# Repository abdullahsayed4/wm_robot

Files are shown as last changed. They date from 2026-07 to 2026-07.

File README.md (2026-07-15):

# WM Robot — Autonomous Mobile Robot for Warehouse Operations





> **Graduation Project** — Faculty of Engineering at Shoubra, Benha University  
> Department of Mechanical & Mechatronics Engineering · 2024–2025  
> **Supervisor:** Dr. Mahmoud Mohamed El-Samanti

---

## Overview

WM Robot is a fully autonomous differential-drive mobile robot designed for indoor warehouse environments. It performs pickup-and-dropoff tasks without human intervention by combining embedded motor control, sensor fusion, autonomous navigation, and a web-based mission interface.

WM Robot

---

## System Architecture

```
┌─────────────────────────────────────────────────────┐
│                   ROS 2 (Jazzy)                     │
│                                                     │
│  ┌──────────────┐    ┌──────────────┐    ┌───────┐  │
│  │ wm_robot_    │    │ wm_robot_    │    │ Nav2  │  │
│  │ hardware     │    │ bringup      │    │ Stack │  │
│  │ (C++)        │    │ (Launch/Cfg) │    │       │  │
│  └──────┬───────┘    └──────────────┘    └───────┘  │
│         │                                           │
│  ┌──────▼───────┐    ┌──────────────┐              │
│  │  TeensyDriver│    │  IMU Node    │              │
│  │  (Serial)    │    │  (Python)    │              │
│  └──────┬───────┘    └──────┬───────┘              │
└─────────│──────────────────│─────────────────────┘
          │                  │
    ┌─────▼──────┐    ┌──────▼───────┐    ┌──────────┐
    │ Teensy 4.1 │    │ Arduino Uno  │    │ RPLIDAR  │
    │ (PID + Enc)│    │ (BNO055 IMU  │    │    A1    │
    └────────────┘    │ + Actuator)  │    └──────────┘
                      └──────────────┘
```

---

## Hardware

| Component | Details |
|---|---|
| **Chassis** | Differential-drive, custom-built |
| **Microcontroller** | Teensy 4.1 (motor PID + encoders) |
| **IMU Controller** | Arduino Uno (BNO055 IMU + linear actuator) |
| **LiDAR** | RPLIDAR A1 |
| **IMU** | BNO055 (9-DOF) |
| **Motors** | DC motors with encoders |
| **Motor Driver** | Cytron |
| **Lift Mechanism** | Scissor lift + linear actuator + limit switches |
| **Joystick** | PlayStation 4 (Bluetooth) |
| **Compute** | Raspberry Pi 4 (ROS 2 host) |

---

## Software Stack

| Layer | Technology |
|---|---|
| **OS** | Ubuntu 24.04 |
| **Middleware** | ROS 2 Jazzy |
| **SLAM** | SLAM Toolbox |
| **Navigation** | Nav2 (AMCL + DWB) |
| **State Estimation** | robot_localization (EKF) |
| **Motor Control** | Custom C++ hardware interface (ros2_control) |
| **IMU Driver** | Python serial node |
| **Mission UI** | React (web-based) |

---

## Repository Structure

```
wm_robot/
├── src/
│   ├── wm_robot_project/        # URDF, meshes, Gazebo worlds, RViz
│   │   ├── urdf/                # Xacro robot description
│   │   ├── meshes/              # STL files (base, wheels, LiDAR, casters)
│   │   ├── launch/              # Display & Gazebo simulation launch
│   │   └── worlds/              # Gazebo SDF world
│   │
│   ├── wm_robot_hardware/       # C++ hardware interface & drivers
│   │   ├── src/
│   │   │   ├── robot_node.cpp               # Main ROS 2 node (50Hz control loop)
│   │   │   ├── cytron_driver.cpp            # Teensy serial driver
│   │   │   └── wm_robot_base_hardware_interface.cpp  # ros2_control plugin
│   │   ├── include/
│   │   │   ├── cytron_driver.hpp
│   │   │   └── wm_robot_base_hardware_interface.hpp
│   │   └── scripts/
│   │       └── imu_node.py      # IMU + actuator node (Arduino Uno)
│   │
│   ├── wm_robot_firmware/       # Arduino/Teensy firmware
│   │   └── firmware/
│   │       └── serial_transmitter/  # Teensy serial protocol
│   │
│   ├── wm_robot_bringup/        # Launch files & configuration
│   │   ├── launch/
│   │   │   ├── robot_launch.py       # Bring up hardware (robot + LiDAR + IMU)
│   │   │   └── navigation_launch.py  # Nav2 navigation stack
│   │   └── config/
│   │       ├── nav2_params.yaml           # Nav2 tuning
│   │       ├── ekf_config.yaml            # EKF sensor fusion
│   │       ├── wm_robot_controllers.yaml  # ros2_control config
│   │       └── Joy_stick.yaml             # PS4 joystick mapping
│   │
│   └── rplidar_ros/             # RPLIDAR A1 ROS 2 driver
│
├── maps/                        # Pre-built occupancy grid maps
│   ├── my_map1.yaml / .pgm
│   ├── my_map2.yaml / .pgm
│   └── my_map3.yaml / .pgm
│
├── start_robot.sh               # Quick startup script
└── README.md
```

---

## Getting Started

### Prerequisites

```bash
# ROS 2 Jazzy
sudo apt install ros-jazzy-desktop

# Dependencies
sudo apt install ros-jazzy-nav2-bringup \
                 ros-jazzy-slam-toolbox \
                 ros-jazzy-robot-localization \
                 ros-jazzy-ros2-control \
                 ros-jazzy-ros2-controllers \
                 ros-jazzy-joy \
                 ros-jazzy-teleop-twist-joy
```

### Build

```bash
mkdir -p ~/wm_robot_ws/src
cd ~/wm_robot_ws/src
git clone https://github.com/YOUR_USERNAME/wm_robot.git .
cd ~/wm_robot_ws
colcon build --symlink-install
source install/setup.bash
```

### Run

**Step 1 — Bring up the robot hardware:**
```bash
ros2 launch wm_robot_bringup robot_launch.py
```

**Step 2 — Start IMU + actuator node:**
```bash
ros2 run wm_robot_hardware imu_node
```

**Step 3 — Run SLAM (mapping mode):**
```bash
ros2 launch slam_toolbox online_async_launch.py
```

**Step 4 — Start navigation with existing map:**
```bash
ros2 launch wm_robot_bringup navigation_launch.py \
  map:=/path/to/maps/my_map1.yaml
```

**Step 5 — Manual control (PS4 Joystick):**
```bash
ros2 launch teleop_twist_joy teleop-launch.py
```

---

## Key Features

- **Autonomous Navigation** — SLAM Toolbox for mapping, Nav2 for localization and path planning
- **Dual PID Control** — Independent PID loops per wheel (MATLAB-tuned + Arduino PID_v1)
- **Sensor Fusion** — LiDAR + IMU + wheel odometry fused via EKF
- **Scissor Lift** — Linear actuator with limit switches for precise payload handling
- **Mock Hardware Mode** — Test navigation without physical robot (`use_mock_hardware:=true`)
- **Web Mission Interface** — React-based UI for mission assignment and monitoring
- **PS4 Teleoperation** — Bluetooth joystick for manual driving during mapping

---

## Serial Protocol

### Teensy 4.1 (ttyACM0) — Motor Controller
- Baud: `115200`
- Format: `A{posL}B{posR}C{velL}D{velR}` (position in rad, velocity in rad/s)

### Arduino Uno (ttyACM1) — IMU + Actuator
- Baud: `115200`
- IMU output: `IMU,{seq},{qw},{qx},{qy},{qz},{gx},{gy},{gz},{ax},{ay},{az},{cal_sys},{cal_gyro},{cal_acc},{cal_mag}`
- Actuator commands: `1\n` (lift up) / `0\n` (lower down)
- Actuator feedback: `LIFT_DONE` / `LOWER_DONE`

---

## Team

| Name |
|------|
| Abdullah Sayed |
| Abanoub Osama |
| Elsayed Azab |
| Amir Magdy |
| Youssef Omar |
| Nourhan Nagy |

**Supervisor:** Dr. Mahmoud Mohamed El-Samanti  
**Institution:** Faculty of Engineering at Shoubra, Benha University

---

## License

This project is licensed under the MIT License — see [LICENSE](LICENSE) for details.

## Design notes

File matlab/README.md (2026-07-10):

# Motor Control — PID Tuning & Low-Pass Filter

This folder contains all MATLAB/Simulink work done for motor system identification, PID tuning, and digital low-pass filter design.

---

## Folder Structure

```
matlab/
├── pid_tuning/
│   ├── pid_tuning.slx       # Simulink model for PID tuning (System Identification)
│   └── importfile.m         # MATLAB script to import collected motor data
│
├── low_pass_filter/
│   ├── LowPassFilter.ipynb              # Low-pass filter design
│   ├── ButterworthFilter.ipynb          # Butterworth filter implementation
│   ├── Analytic Derivation for Low-Pass 2.0.ipynb  # Mathematical derivation
│   └── filter_response.png              # Filter frequency response plot
│
└── firmware/
    ├── motor1_pid.ino        # Motor 1 — Custom PID + Digital Filter (Teensy)
    └── motor2_pid.ino        # Motor 2 — Two-motor PID implementation
```

---

## PID Parameters (Motor 1)

Tuned via MATLAB System Identification Toolbox from real motor step response data:

| Parameter | Value |
|---|---|
| **Kp** | 19.15 |
| **Ki** | 306.0 |
| **Kd** | 0.055 |
| **Sample Time** | 20 ms (50 Hz) |
| **Output Limits** | -250 to +250 (PWM) |

---

## Low-Pass Filter Design

A 2nd-order digital low-pass filter was derived analytically using the **Bilinear Transform** (Tustin method):

- **Cutoff Frequency:** Fc = 2.5 Hz
- **Sample Time:** dt = 0.020 s
- **Method:** Butterworth → Bilinear Transform

**Filter Coefficients:**
```
alpha = 0.728490
beta  = 0.135755
```

**Difference Equation:**
```
y[n] = alpha * y[n-1] + beta * x[n] + beta * x[n-1]
```

The filter smooths raw encoder velocity readings before feeding them into the PID controller, eliminating electrical noise without introducing significant lag.

---

## Methodology

1. **Data Collection** — Motor driven open-loop, encoder data logged via Serial at 50 Hz
2. **System Identification** — MATLAB `System Identification Toolbox` used to fit a transfer function to the collected step response data
3. **PID Tuning** — Simulink PID Tuner used to find optimal Kp, Ki, Kd
4. **Filter Design** — Butterworth filter analytically derived and discretized via Bilinear Transform
5. **Validation** — PID + filter tested on real hardware with square wave setpoint tracking

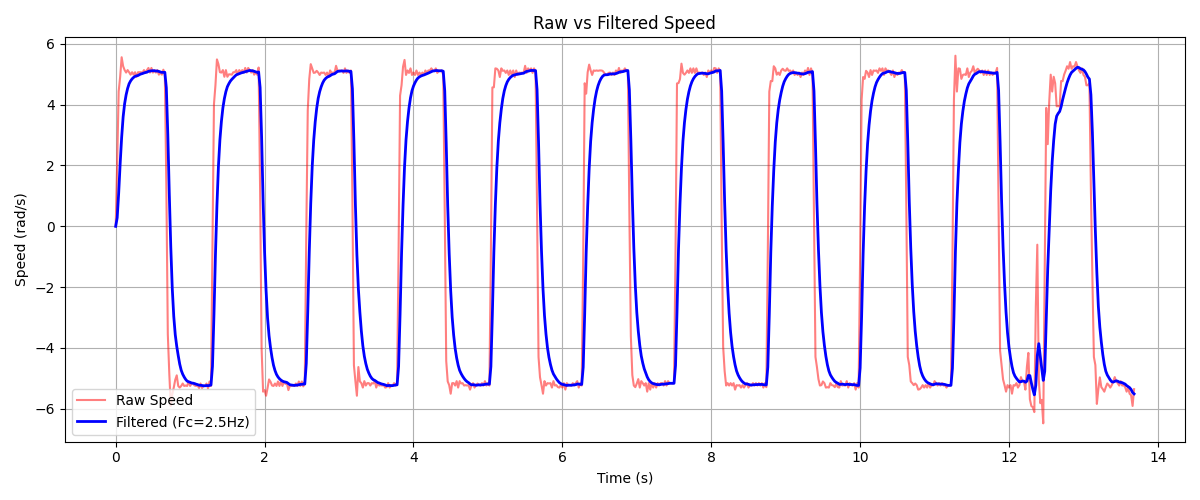
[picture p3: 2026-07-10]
matlab/low_pass_filter/filter_response.png

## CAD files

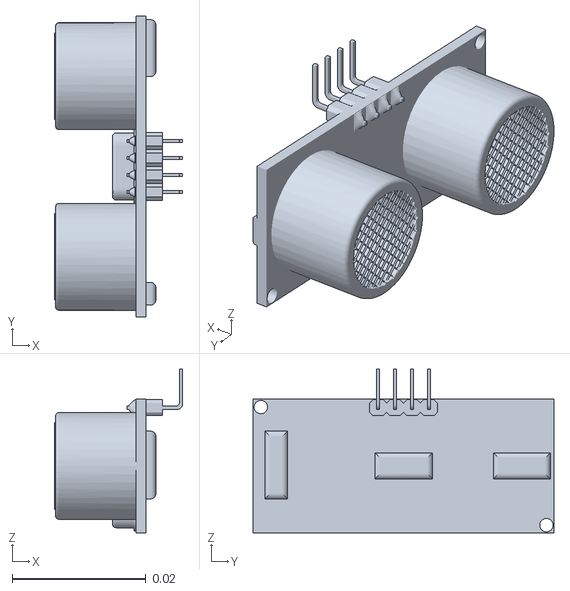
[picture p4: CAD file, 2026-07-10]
src/wm_robot_project/meshes/soni2.STL
0.0192 x 0.045 x 0.0245

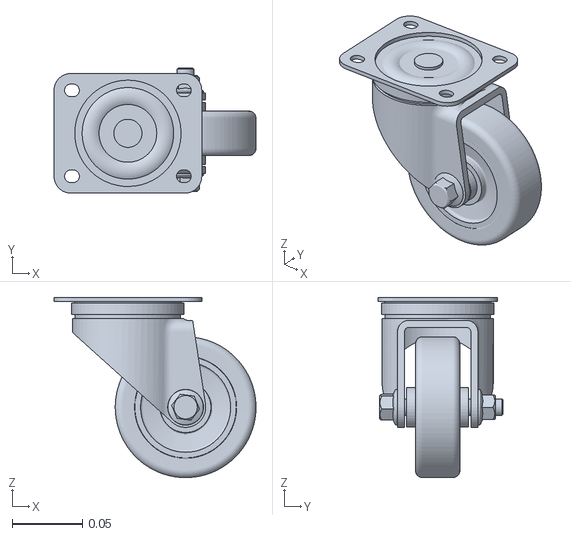
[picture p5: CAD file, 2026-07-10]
src/wm_robot_project/meshes/caster1.STL
0.143 x 0.089 x 0.128

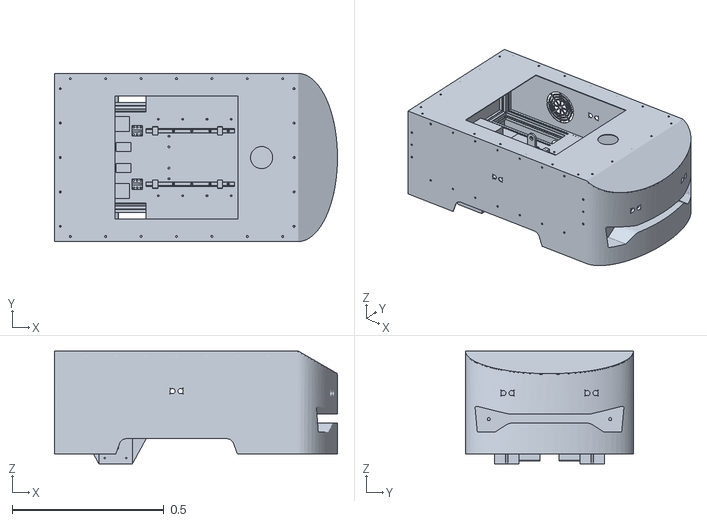
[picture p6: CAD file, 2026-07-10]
src/wm_robot_project/meshes/base_link.STL
0.932 x 0.554 x 0.372

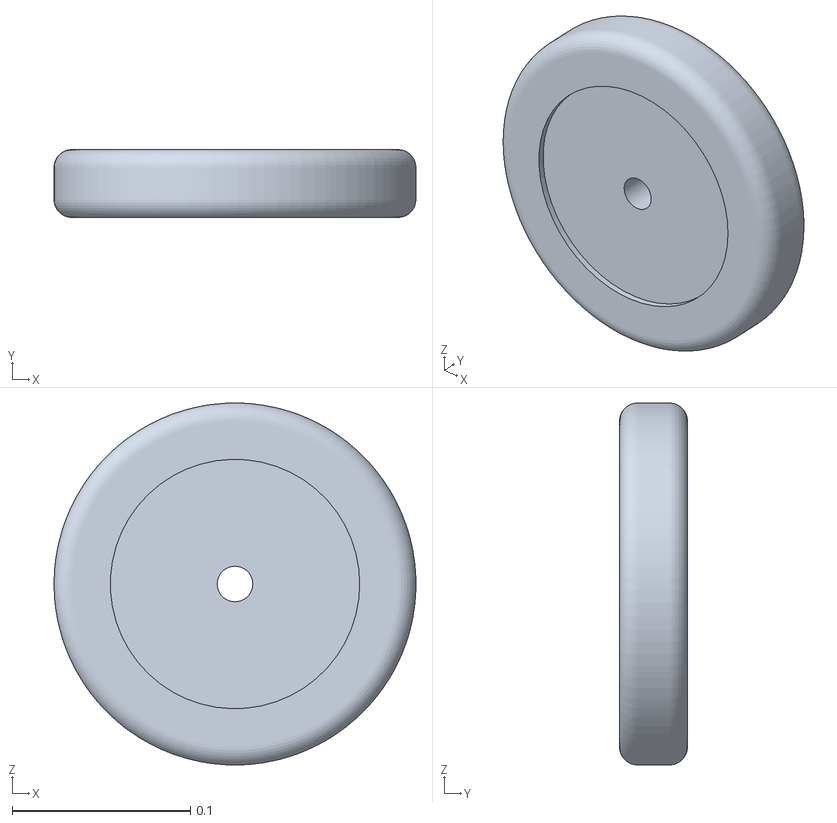
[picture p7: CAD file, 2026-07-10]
src/wm_robot_project/meshes/wheel1.STL
0.203 x 0.0381 x 0.203

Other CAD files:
src/wm_robot_project/meshes/soni3.STL
src/wm_robot_project/meshes/soni5.STL
src/wm_robot_project/meshes/caster2.STL
src/wm_robot_project/meshes/soni1.STL
src/wm_robot_project/meshes/wheel2.STL
src/wm_robot_project/meshes/soni4.STL

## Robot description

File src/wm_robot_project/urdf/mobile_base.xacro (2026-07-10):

<?xml version="1.0"?>
<robot xmlns:xacro="http://www.ros.org/wiki/xacro">
    <xacro:property name="wheel_radius" value="0.1"/>
    <xacro:property name="wheel_length" value="0.05"/>
    <xacro:macro name="cylinder_inertia" params="m r l o_xyz o_rpy">
        <inertial>
            <mass value="${m}"/>
            <origin xyz="${o_xyz}" rpy="${o_rpy}"/>
            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
        </inertial>
    </xacro:macro>

    <xacro:macro name="sphere_inertia" params="m r o_xyz o_rpy">
        <inertial>
            <mass value="${m}"/>
            <origin xyz="${o_xyz}" rpy="${o_rpy}"/>
            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
        </inertial>
    </xacro:macro>
  <link name="base_footprint"/>

  <link name="base_link">
    <inertial>
      <origin xyz="0.0037146 -0.00045656 0.12116" rpy="0 0 0" />
      <mass value="25.079" />
      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
    </inertial>
    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
  </link>

  <link name="soni1">
    <inertial>
      <origin xyz="-0.0025046 -1.8888E-05 -4.9385E-05" rpy="0 0 0" />
      <mass value="0.0044896" />
      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
    </inertial>
    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
  </link>

  <joint name="s_j1" type="fixed">
    <origin xyz="-0.3965 0 0.185" rpy="0 0 0" />
    <parent link="base_link" />
    <child link="soni1" />
  </joint>

  <link name="soni2">
    <inertial>
      <origin xyz="-0.0025046 -1.8888E-05 -4.9385E-05" rpy="0 0 0" />
      <mass value="0.0044896" />
      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
    </inertial>
    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
  </link>

  <joint name="s_j2" type="fixed">
    <origin xyz="0 0.2715 0.185" rpy="-3.1416 0 -1.5708" />
    <parent link="base_link" />
    <child link="soni2" />
  </joint>

  <link name="soni3">
    <inertial>
      <origin xyz="-0.0025046 -1.8888E-05 -4.9385E-05" rpy="0 0 0" />
      <mass value="0.0044896" />
      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
    </inertial>
    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
  </link>

  <joint name="s_j3" type="fixed">
    <origin xyz="0.49478 -0.1384 0.1784" rpy="3.1416 0 3.1416" />
    <parent link="base_link" />
    <child link="soni3" />
  </joint>

  <link name="soni4">
    <inertial>
      <origin xyz="-0.0025046 -1.8888E-05 -4.9385E-05" rpy="0 0 0" />
      <mass value="0.0044896" />
      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
    </inertial>
    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
  </link>

  <joint name="s_j4" type="fixed">
    <origin xyz="0.49449 0.1384 0.1784" rpy="3.1416 0 3.1416" />
    <parent link="base_link" />
    <child link="soni4" />
  </joint>

  <link name="soni5">
    <inertial>
      <origin xyz="-0.0025046 -1.8888E-05 -4.9385E-05" rpy="0 0 0" />
      <mass value="0.0044896" />
      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
    </inertial>
    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
  </link>

  <joint name="s_j5" type="fixed">
    <origin xyz="0 -0.2715 0.185" rpy="0 0 1.5708" />
    <parent link="base_link" />
    <child link="soni5" />
  </joint>

  <link name="wheel1">
    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
    <xacro:cylinder_inertia m="1.0762" r="${wheel_radius}" l="${wheel_length}" o_xyz="0 0 0" o_rpy="${pi / 2.0} 0 0"/>
  </link>



  <joint name="wheel1_j" type="continuous">
    <origin xyz="-0.2007 0.2 0" rpy="0 0 0" />
    <parent link="base_link" />
    <child link="wheel1" />
    <axis xyz="0 1 0" />
  </joint>

  <link name="wheel2">
    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
    <xacro:cylinder_inertia m="1.0762" r="${wheel_radius}" l="${wheel_length}" o_xyz="0 0 0" o_rpy="${pi / 2.0} 0 0"/>
  </link>

  <joint name="wheel2_j" type="continuous">
    <origin xyz="-0.2007 -0.2 0" rpy="0 0 0" />
    <parent link="base_link" />
    <child link="wheel2" />
    <axis xyz="0 1 0" />
  </joint>

  <link name="caster1">
    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
  <xacro:sphere_inertia m="0.35" r="${wheel_radius / 2.0}" o_xyz="0 0 0" o_rpy="0 0 0"/>
  </link>

  <joint name="caster1_j" type="fixed">
    <origin xyz="0.27848 -0.19038 -0.0516" rpy="0 0 0" />
    <parent link="base_link" />
    <child link="caster1" />
  </joint>

  <link name="caster2">
    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
  <xacro:sphere_inertia m="0.35" r="${wheel_radius / 2.0}" o_xyz="0 0 0" o_rpy="0 0 0"/>
  </link>

  <joint name="caster2_j" type="fixed">
    <origin xyz="0.27848 0.19557 -0.0516" rpy="0 0 0" />
    <parent link="base_link" />
    <child link="caster2" />
  </joint>

  <link name="lidar">
    <inertial>
      <origin xyz="0.01206 -0.00053212 -0.028765" rpy="0 0 0" />
      <mass value="0.073085" />
      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
    </inertial>
    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
  </link>

  <joint name="lidar_j" type="fixed">
    <origin xyz="0.28 -0.0002 0.3344" rpy="0 0 0" />
    <parent link="base_link" />
    <child link="lidar" />
  </joint>

  <joint name="base_joint" type="fixed">
        <parent link="base_footprint"/>
        <child link="base_link"/>
        <origin xyz="0 0 0.1016" rpy="0 0 0"/>
  </joint>
  
</robot>

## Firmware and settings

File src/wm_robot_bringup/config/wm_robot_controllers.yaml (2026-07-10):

controller_manager:
  ros__parameters:
    update_rate: 50

    joint_state_broadcaster:
      type: joint_state_broadcaster/JointStateBroadcaster

    diff_drive_controller:
      type: diff_drive_controller/DiffDriveController

diff_drive_controller:
  ros__parameters:
    left_wheel_names: ["wheel1_j"]
    right_wheel_names: ["wheel2_j"]

    wheel_radius: 0.1
    wheel_separation: 0.4
    wheel_separation_multiplier: 1.0
    left_wheel_radius_multiplier: 1.0
    right_wheel_radius_multiplier: 1.0

    odom_frame_id: "odom"
    base_frame_id: "base_footprint"
    pose_covariance_diagonal: [0.001, 0.001, 0.001, 0.001, 0.001, 0.01]
    twist_covariance_diagonal: [0.001, 0.001, 0.001, 0.001, 0.001, 0.01]
    enable_odom_tf: true
    publish_rate: 50.0

    linear.x.max_velocity: 1.0
    linear.x.min_velocity: -1.0
    linear.x.max_acceleration: 1.0
    linear.x.max_jerk: 0.0
    linear.x.min_jerk: 0.0

    angular.z.max_velocity: 1.0
    angular.z.min_velocity: -1.0
    angular.z.max_acceleration: 1.0
    angular.z.min_acceleration: -1.0
    angular.z.max_jerk: 0.0
    angular.z.min_jerk: 0.0

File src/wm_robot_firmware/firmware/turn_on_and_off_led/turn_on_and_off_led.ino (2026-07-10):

#define Led_PIN 13

void setup() {
  Serial.begin(115200);
  pinMode(Led_PIN, OUTPUT);
  digitalWrite(Led_PIN, LOW);
}

void loop() {
  if (Serial.available()) {
    int x = Serial.readString().toInt();

    if (x == 0) {
      digitalWrite(Led_PIN, LOW);
    } else {
      digitalWrite(Led_PIN, HIGH);
    }
  }
}

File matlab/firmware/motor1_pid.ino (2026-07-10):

#include <Arduino.h>
#include "CytronMotorDriver.h"
#include <Encoder.h>
#include <PID_v1.h>

// ================= MOTOR & ENCODER =================
CytronMD motor(PWM_DIR, 3,4) ;
Encoder myEnc(1, 2);

// ================= VARIABLES =================
long prevCount = 0;
unsigned long lastTime = 0;
double N = 1440.0;

// ================= FILTER COEFFICIENTS =================
// Fc = 2.5 Hz, dt = 0.020s (Bilinear Transform)
double alpha = 0.728490;
double beta  = 0.135755;
double xn1 = 0.0;   // السرعة الخام السابقة
double yn1 = 0.0;   // السرعة المفلترة السابقة

// ================= PID SETTINGS =================
double Setpoint, Input, Output;
double Kp = 19.15;
double Ki = 306.0;
double Kd = 0.055;

PID myPID(&Input, &Output, &Setpoint, Kp, Ki, Kd, DIRECT);

void setup() {
  Serial.begin(9600);
  //pinMode(2, INPUT_PULLUP);
 // pinMode(3, INPUT_PULLUP);
  delay(3000);

  Setpoint = 5.0;
  myPID.SetMode(AUTOMATIC);
  myPID.SetSampleTime(20);
  myPID.SetOutputLimits(-250, 250);
  lastTime = millis();
}

void loop() {
  unsigned long now = millis();

  if (now - lastTime >= 20) {
    double dt = (now - lastTime) / 1000.0;
    lastTime = now;

    // حساب السرعة الخام
    long count = myEnc.read();
    long delta = count - prevCount;
    prevCount = count;
    double rawSpeed = ((double)delta / N) * (2.0 * PI / dt);

    // تطبيق الفلتر
    double xn = rawSpeed;
    double yn = (alpha * yn1) + (beta * xn) + (beta * xn1);

    // تحديث القيم السابقة
    xn1 = xn;
    yn1 = yn;

    // الـ PID يشتغل على السرعة المفلترة
    Input = yn;
    myPID.Compute();
    motor.setSpeed((int)Output);

    // طباعة البيانات
    Serial.print("Time:");
    Serial.print(now);
    Serial.print(",Target:");
    Serial.print(Setpoint);
    Serial.print(",FilteredSpeed:");
    Serial.print(yn, 4);
    Serial.print(",RawSpeed:");
    Serial.print(rawSpeed, 4);
    Serial.print(",PWM:");
    Serial.println((int)Output);
  }
}

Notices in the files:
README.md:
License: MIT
